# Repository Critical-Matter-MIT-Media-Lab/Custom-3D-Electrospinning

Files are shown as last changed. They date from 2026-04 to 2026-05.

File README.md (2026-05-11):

<div align="center">

# Custom 3D Electrospinning

### A robotic platform for three-dimensional, field-conditioned nanofiber fabrication

*An open hardware + firmware companion to the SIGGRAPH 2026 paper*

**[Electrospun Fields: 3D Nano-Fiber Material Computation as Design Method](#-publications)**

[Critical Matter Group](https://www.media.mit.edu/groups/critical-matter/overview/) · MIT Media Lab

</div>

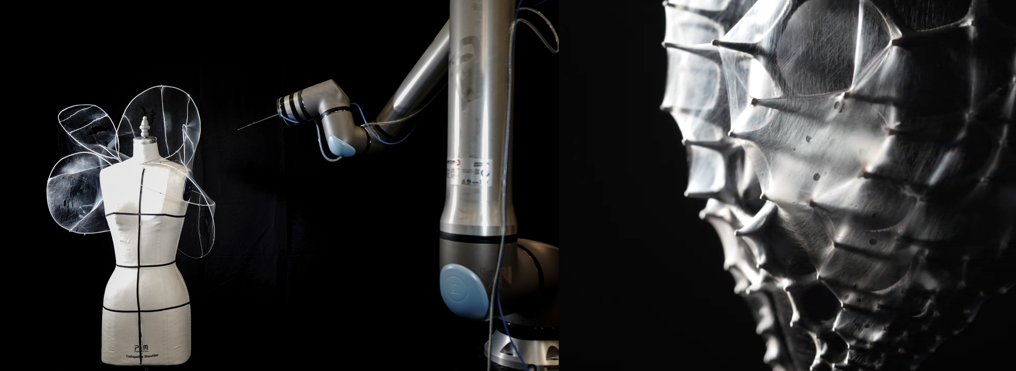
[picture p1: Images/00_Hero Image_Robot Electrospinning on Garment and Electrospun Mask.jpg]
Hero — UR20 robotic arm electrospinning onto a wire garment, alongside a close-up of an electrospun conductive PLA mask


---

## What this repository is

This repo is a **practical companion** to our SIGGRAPH 2026 paper. The paper presents the *why* — a material-computational design method built around electrospinning. This repository is the *how* — the CAD files, firmware, and step-by-step guides you need to build a custom 3D electrospinning rig of your own.

It is intended for:

- **Researchers** who want to reproduce or extend our platform.
- **Designers, artists, and makers** curious about electrospinning as a fabrication method.
- **Students** picking up electrospinning for the first time.

> [!NOTE]
> This repo is meant to **grow over time**. As we publish further work and refine the platform, we will keep adding CAD revisions, firmware features, materials notes, and tutorials.

---

## ▶ Start here: the build tutorial

The fastest way to understand the full system is to watch our build tutorial. It walks through the mechanical, electrical, and software setup end-to-end.

<div align="center">

Watch the tutorial on YouTube (https://youtu.be/FIuRhwlGrd0)

**[▶ Watch on YouTube](https://youtu.be/FIuRhwlGrd0)**

</div>

If you are new to electrospinning, we recommend reading the next two sections first, then watching the tutorial.

---

## What is electrospinning?

Electrospinning is a fabrication technique that uses **strong electric fields to draw a continuous jet of polymer solution into ultra-fine fibers** — typically between a few hundred nanometers and a few micrometers in diameter. The result is a nonwoven fibrous mat with extremely high surface area.

A traditional, fixed setup looks like this:

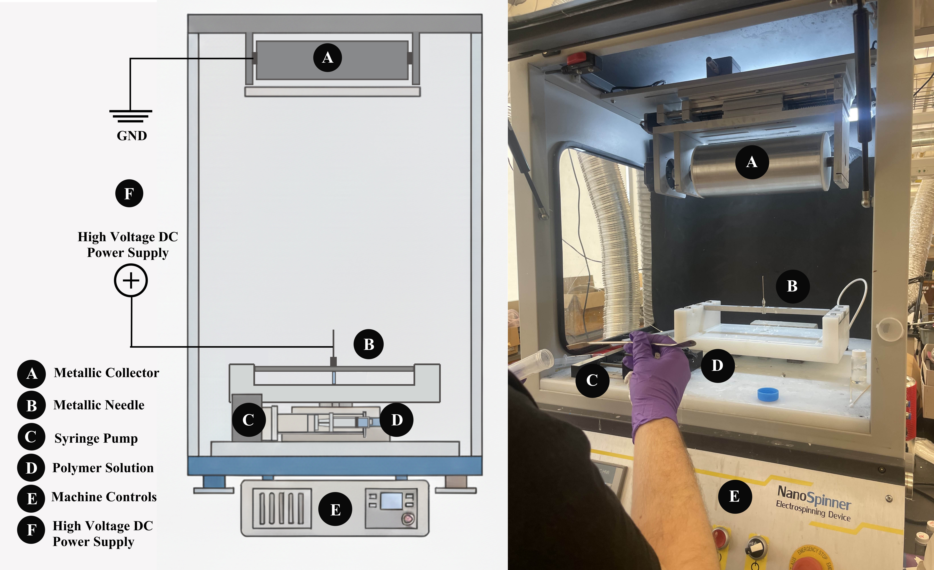
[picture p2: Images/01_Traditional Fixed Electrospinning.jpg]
Traditional fixed electrospinning setup — labeled diagram and lab photograph showing the metallic collector, metallic needle, syringe pump, polymer solution, machine controls, and high-voltage DC power supply


The four functional elements are:

1. **A polymer solution** — a polymer dissolved in a suitable solvent.
2. **A syringe pump** — meters the solution at a controlled flow rate (typically 0.1 – 1 mL/hr).
3. **A high-voltage DC power supply** — connected to a metallic needle, charging the polymer jet (typically **15 – 25 kV**).
4. **A grounded conductive collector** — the substrate the fibers deposit onto.

When the electric field overcomes the surface tension of the droplet at the needle tip, a thin jet is drawn out, whips through the air (stretching as it travels), and the solvent evaporates before deposition — leaving solid nanofibers on the collector.

Electrospinning has been widely used in filtration, tissue engineering, and surface coatings. **What our work explores is its potential as a *spatial, three-dimensional* fabrication method.**

---

## Why a *custom 3D* electrospinning rig?

Conventional electrospinning is essentially a 2D process — fibers fall onto a flat collector below the needle. This makes it excellent for uniform fiber mats, but **fundamentally limits volumetric and topological control**.

In our paper we show that **scaffold curvature shapes the electric field**, and the field shapes where fibers deposit. Convex regions accumulate fibers consistently; concave regions experience *field shielding* and remain bare. To work around that and access complex 3D topologies, the emitter itself needs to move and reorient relative to the scaffold.

That is what this platform does. It mounts an electrospinning end-effector on a six-axis **Universal Robots UR20** arm, with a **localized syringe pump** so flow stays consistent regardless of orientation, and routes high voltage directly to the robot-mounted needle.

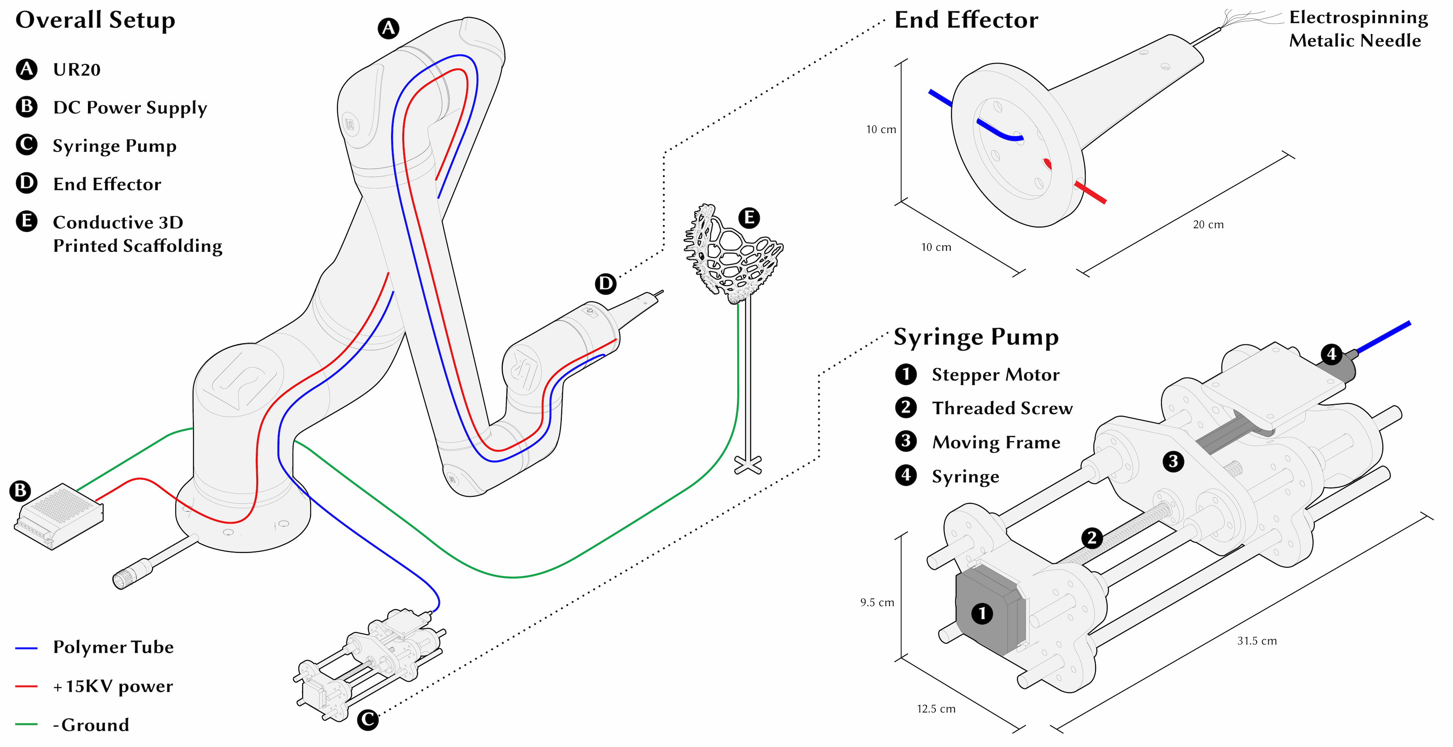
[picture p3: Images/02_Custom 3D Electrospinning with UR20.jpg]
Custom 3D Electrospinning platform — full setup with UR20, DC power supply, syringe pump, end effector, and conductive 3D-printed scaffolding, with detail callouts for the end effector and the syringe pump


| Letter | Component |
|---|---|
| **A** | UR20 six-axis robotic arm |
| **B** | High-voltage DC power supply |
| **C** | Syringe pump (custom — see [`CAD Models/`](CAD%20Models) and [`Arduino Code/`](Arduino%20Code)) |
| **D** | End effector — routes polymer + high voltage to the needle |
| **E** | Conductive 3D-printed scaffolding (the substrate fibers deposit onto) |

> Before building or operating this platform, read the [Safety](#-safety) section below.

---

## What's in this repository

| Folder | What's inside |
|---|---|
| [`Images/`](Images) | Figures from the paper and additional photographs (hero shots, application images, microscopy) |
| [`CAD Models/`](CAD%20Models) | STEP files for every printable / fabricated part of the syringe pump |
| [`Arduino Code/`](Arduino%20Code) | ESP32 firmware for the syringe pump — exposes a Wi-Fi web UI for flow-rate control |
| [`Publications/`](Publications) | Links to publications associated with this platform |

---

## ⚠ Safety

> [!WARNING]
> **Electrospinning involves high-voltage DC and volatile solvents. Read this section before powering on or building anything.**

This platform operates at **up to 25 kV DC** and dispenses polymer solutions prepared with organic solvents. Both are serious hazards and must be respected. The same safety guidance that applies in our paper applies here.

### High voltage

- **Proper electrical insulation and grounding are strictly required.** All conductive paths intended to be at high potential must be sleeved in HV-rated insulation; all conductive paths intended to be at ground must be continuously, verifiably tied to earth ground.
- **Maintain a safe standoff distance.** Never make physical contact with the emitter, polymer jet, or scaffold while the system is energized.
- **De-energize and discharge before touching anything.** Switch off and disconnect the HV supply, then short the needle to ground (with an insulated grounding stick) before approaching the emitter — even a powered-off supply can leave residual charge.
- **One person at the controls.** When the supply is energized, only one trained operator should be near the rig.

### Solvents and ventilation

The polymer solutions used in our paper involve solvents such as **water, formic acid, and lithium bromide**, and may include **calcium chloride** as an additive. Solvent vapor accumulates near the emitter during electrospinning.

- **Operate inside a fume hood** or a dedicated, well-ventilated electrospinning enclosure.
- **No open flames, no sparks, no ignition sources** anywhere near the emitter — solvent vapor + a high-voltage corona is a fire hazard.
- **Wear appropriate PPE:** nitrile gloves, safety glasses, and a lab coat at minimum. Refer to the SDS for each specific solvent you use.

### Robotic arm

This platform integrates a **Universal Robots UR20** six-axis arm.

- **Follow your robot's standard safety protocol.** Define a safety-rated workspace, use the e-stop, and keep humans out of the cell during programmed motion.
- **Coordinate the HV and motion systems.** The robot should not be commanded to move when an operator is positioned to manually adjust the scaffold or the emitter — and HV must be off whenever the cell is entered.

### Bottom line

If you are unsure whether your setup is safe, **stop, ask, and verify** before proceeding. None of the contents of this repository should be treated as a substitute for proper lab training, institutional safety review, or supervision by a qualified electrical and chemical safety officer.

---

## Mechanical setup

The mechanical side of this platform is the **custom syringe pump** — a high-torque, hand-buildable design that mounts to the robot's end effector and pumps polymer solution at electrospinning-grade flow rates (typically 0.1 – 5 mL/hr).

| Element | Role |
|---|---|
| ① Stepper motor | Drives the leadscrew under microstepped pulses from the ESP32 |
| ② Threaded screw (leadscrew) | Converts rotation into linear translation of the moving frame |
| ③ Moving frame | Linear-bearing-guided carriage that pushes the syringe plunger |
| ④ Syringe | Disposable polymer reservoir with a metallic needle |

All mechanical parts are provided as STEP files in [`CAD Models/`](CAD%20Models). See the README in that folder for a part-by-part inventory and printing notes.

---

## Electrical setup

Three independent circuits coexist on this platform — keep them mentally separate:

| Wiring (matches the diagram above) | Carries | Voltage |
|---|---|---|
| **Blue** — polymer tube | Polymer solution from syringe pump → needle | n/a |
| **Red** — high-voltage line | DC power from supply → needle | **+15 to +25 kV** |
| **Green** — ground | DC power supply ground → conductive scaffold | 0 V (earth) |

Plus a low-voltage DC line (not shown in the simplified diagram) powering the ESP32 + stepper driver inside the syringe pump enclosure — covered in [`Arduino Code/README.md`](Arduino%20Code).

> [!CAUTION]
> The high-voltage red line and the polymer tubing both physically run alongside the robot arm to reach the end effector. Use HV-rated insulated tubing, secure all routing, and verify continuity to the grounded scaffold *before* energizing the supply.

---

## Programming setup

The syringe pump is controlled by an **ESP32** running the firmware in [`Arduino Code/`](Arduino%20Code). The firmware:

- Creates its own **Wi-Fi access point** (`ESP32-Syringe`) — no router needed.
- Serves a web UI at `http://192.168.4.1` for **flow rate (mL/hr)**, **direction**, and **syringe size**.
- Drives the stepper at microsecond precision via a hardware timer.

Quickstart:

1. Open `Arduino Code/KeratinStepperMotorControl.ino` in the Arduino IDE.
2. Install the ESP32 board package and upload to your ESP32.
3. Connect your phone or laptop to the `ESP32-Syringe` Wi-Fi network.
4. Open `http://192.168.4.1` in a browser, set your flow rate, press **Start**.

Full wiring map, syringe-size calibration, and the underlying flow-rate formula are in [`Arduino Code/README.md`](Arduino%20Code).

---

## Gallery

A small selection of artifacts produced with this platform — see the paper for the full discussion.

| | |
|---|---|
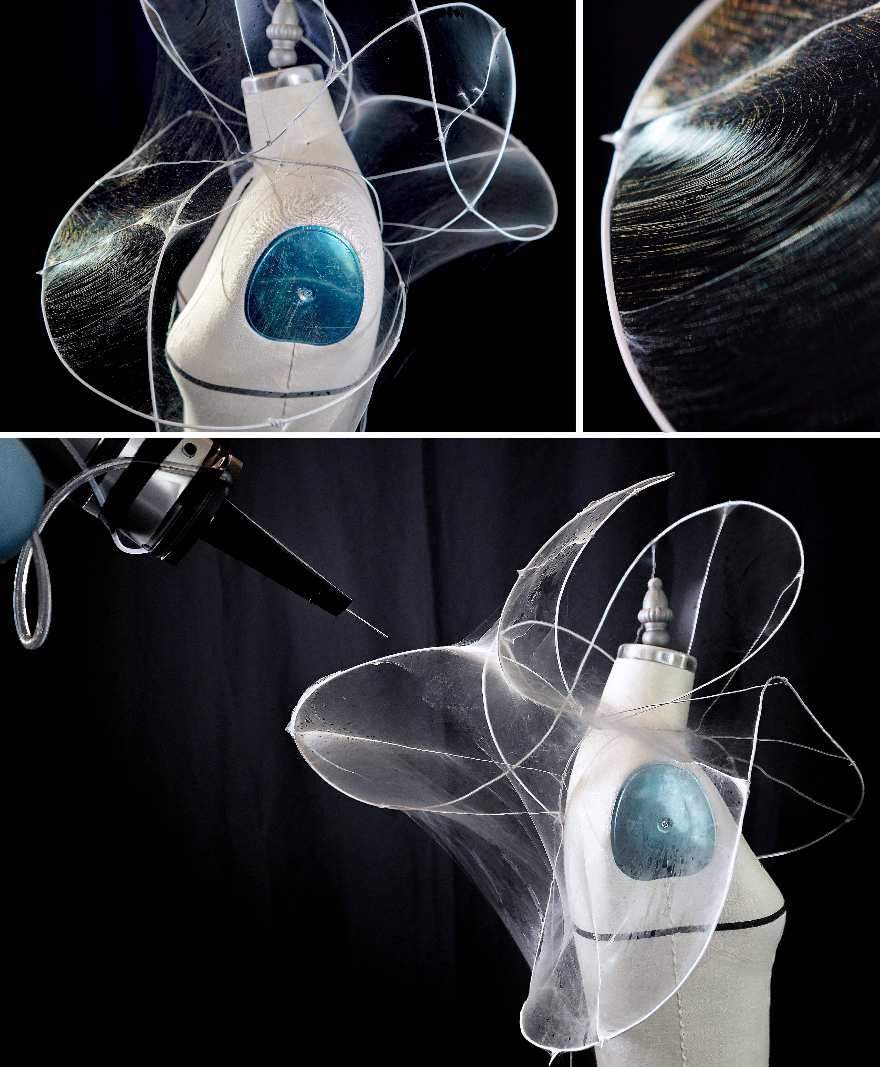
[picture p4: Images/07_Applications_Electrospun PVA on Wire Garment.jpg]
Electrospun PVA on a wire garment, draped on a mannequin
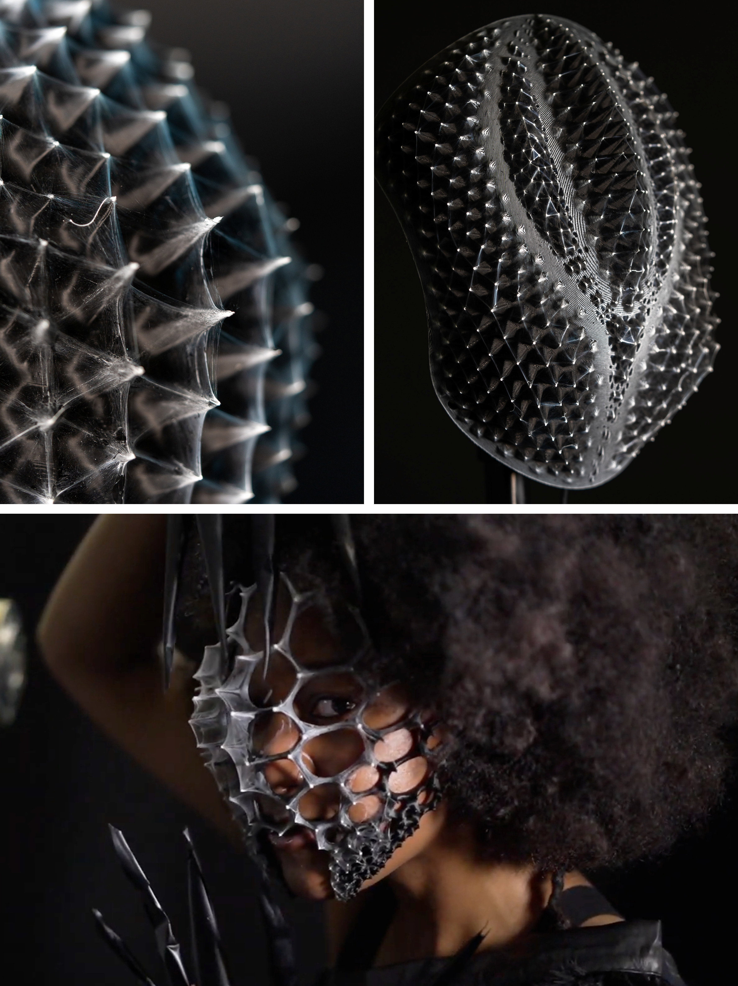
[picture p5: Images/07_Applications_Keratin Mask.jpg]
Electrospun keratin face mask, close-up of fiber surface
|  |  |
| **Electrospun PVA on a wire garment** | **Keratin–PEO face mask** |
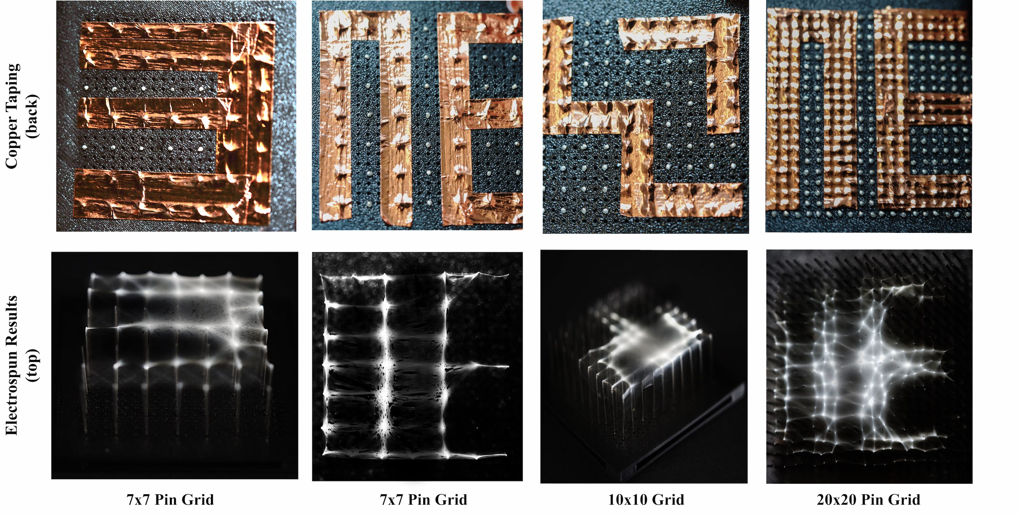
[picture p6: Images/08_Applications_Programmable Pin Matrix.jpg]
Programmable pin-matrix collector with selectively electrospun regions
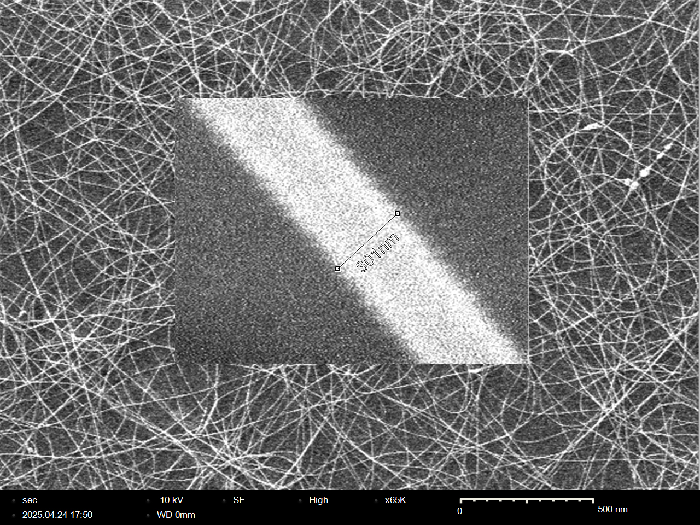
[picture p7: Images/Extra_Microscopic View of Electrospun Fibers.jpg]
Microscopic view of electrospun fibers showing nanoscale fiber morphology
|  |  |
| **Programmable pin-matrix collector** | **Microscopy of electrospun fibers** |

---

## Publications

Work from this platform is documented in the following publications. We host **links only** — please cite the canonical version of record at the publisher when available.

- **Wan, Mahmoud, Mutis, Velho, Xing, Farahi.** *Electrospun Fields: 3D Nano-Fiber Material Computation as Design Method.* SIGGRAPH '26 Art Papers. *ACM Digital Library link coming soon.*

A full list with citation entries lives in [`Publications/README.md`](Publications).

---

## Citation

This paper will appear in the ACM Digital Library shortly. The entry below will be updated with the DOI when available — for now, please use this preliminary BibTeX:

```bibtex
@inproceedings{wan2026electrospun,
  title     = {Electrospun Fields: 3D Nano-Fiber Material Computation as Design Method},
  author    = {Wan, Wai Lok and Mahmoud, Ayah and Mutis, Sergio and Velho, Avantika and Xing, Annie and Farahi, Behnaz},
  booktitle = {ACM SIGGRAPH 2026 Art Papers},
  year      = {2026},
  publisher = {ACM},
  address   = {New York, NY, USA},
  note      = {In press}
  % doi    = {TODO: add DOI when ACM DL link is live}
  % url    = {TODO: add ACM DL URL when available}
}
```

---

## Authors and Acknowledgements

| Author | Affiliation |
|---|---|
| Wai Lok Wan | MIT |
| Ayah Mahmoud | MIT |
| Sergio Mutis | MIT |
| Avantika Velho | Harvard University |
| Annie Xing | Harvard University |
| James Xiao | MIT |
| Behnaz Farahi (Director, [Critical Matter Group](https://www.media.mit.edu/groups/critical-matter/overview/)) | MIT Media Lab |

For questions, collaboration inquiries, or to flag issues with the documentation, please open a GitHub issue on this repository.

### Acknowledgements

We would like to acknowledge Frank (Haotian) Cong and Berfin Ataman for their invaluable contributions to the early development of the system. Our thanks also go to Paolo Salvagione for his guidance on mechanical and electrical engineering. This research was developed in collaboration with the Rutledge Research Group at the MIT Department of Chemical Engineering; we extend our sincere gratitude to Nathan Ewell and Greg Rutledge for their expertise and generous assistance. Finally, we gratefully acknowledge the MIT–LUMA Grant for their generous financial support.

---

## License

© 2026 Critical Matter Group, MIT Media Lab.

This repository — including its source code, CAD files, images, and written documentation — is released under the [Creative Commons Attribution 4.0 International License (CC-BY-4.0)](LICENSE). You are free to share and adapt the contents for any purpose, including commercially, **provided you give appropriate credit to the Critical Matter Group**.

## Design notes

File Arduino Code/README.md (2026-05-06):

# Arduino Code — ESP32 Syringe Pump Firmware

This folder contains the firmware that drives the custom syringe pump.

It runs on an **ESP32**, drives a **NEMA-17 stepper** through a **DRV8825** driver, and exposes a small **Wi-Fi web UI** for setting flow rate, direction, and syringe size — no router needed.

---

## File

- `KeratinStepperMotorControl.ino` — single-file Arduino sketch. The name is a leftover from our keratin-electrospinning experiments; the firmware itself is fully general and works for any polymer.

---

## What it does

- **Creates a Wi-Fi access point** named `ESP32-Syringe` (open, no password by default).
- **Serves a web UI at `http://192.168.4.1`** with controls for:
  - **Start / Pause**
  - **Direction** (clockwise = dispense, counter-clockwise = retract)
  - **Syringe size** (mm of plunger travel per mL)
  - **Flow rate** (mL/hr)
- **Drives the stepper at microsecond precision** via an ESP32 hardware timer running at 1 MHz. The web UI never touches the step pin — it only updates the timer's half-period.

---

## Hardware

| Component | Spec |
|---|---|
| Microcontroller | ESP32 (any DevKit-style board with the standard pinout) |
| Stepper driver | DRV8825 with at least 12–24 V motor supply and 64× microstepping enabled |
| Stepper motor | NEMA-17 bipolar, 200 steps/rev |
| Leadscrew | T8 × 2 (2 mm lead) — see [`CAD Models/`](../CAD%20Models) |

### Wiring

| ESP32 GPIO | DRV8825 pin | Notes |
|---|---|---|
| GPIO **17** | `STEP` | Pulse train output |
| GPIO **16** | `DIR` | HIGH = clockwise, LOW = counter-clockwise |
| GND | `GND` (logic) | Common ground with ESP32 |
| — | `SLEEP` ↔ `RESET` | Tie together to keep the driver awake |
| — | `M0`, `M1`, `M2` | All HIGH for **64× microstepping** (or pull `M2` HIGH and tie `M0/M1` per the DRV8825 datasheet — the firmware assumes 64×) |

The motor power supply (12–24 V) connects to the `VMOT` / `GND` pair on the driver; **be sure to add the recommended 100 µF electrolytic capacitor across `VMOT` and `GND`** as close to the driver as possible.

> [!CAUTION]
> Make sure the stepper logic ground and the motor power ground are common with the ESP32 ground. Floating grounds are a common cause of missed steps and erratic behavior.

---

## How the flow rate is computed

The firmware converts the user-set flow rate (mL/hr) into a step pulse half-period (µs) using:

```
halfPeriodUs = (281,250 × mm_per_mL) / mL_per_hr
```

This number comes from the gearing math at the top of the sketch:

- **Stepper:** 200 steps/rev × 64 microsteps = **12,800 µsteps/rev**
- **Leadscrew:** **2 mm/rev**
- **=> 6,400 µsteps per mm**

If you change the leadscrew, microstepping, or stepper, **update the constant accordingly** — see the comment block at the top of `KeratinStepperMotorControl.ino`.

### Syringe-size calibration

The web UI's **Syringe size** dropdown sets `mm_per_mL` — the millimeters of plunger travel that correspond to 1 mL of dispensed volume. Defaults included:

| Option | Use when |
|---|---|
| `1 mm = 1 mL` | (Default — calibrated for our typical disposable syringe) |
| `2 mm = 1 mL` | Smaller-bore syringes |
| `0.5 mm = 1 mL` | Larger-bore syringes |

To add a new option, edit the `<select id="syringe">` block in the embedded HTML inside the `.ino` file (search for `CHANGE THESE FOR CHANGING SYRINGE OPTIONS`).

> [!TIP]
> The most reliable way to calibrate a new syringe is empirical: dispense for a fixed time at a known mL/hr setting, weigh the output, and adjust `mm_per_mL` until the weight matches the expected volume.

---

## Quickstart

1. **Install the ESP32 board package** in the Arduino IDE.
   - `File → Preferences → Additional Boards Manager URLs:` add `https://espressif.github.io/arduino-esp32/package_esp32_index.json`
   - `Tools → Board Manager`, search **esp32**, install **esp32 by Espressif Systems**.
2. **Open `KeratinStepperMotorControl.ino`** in the Arduino IDE.
3. **Select your ESP32 board** under `Tools → Board → ESP32 Arduino`.
4. **Upload** to the ESP32.
5. Open the **Serial Monitor** at 115200 baud — you should see the access-point IP printed (`192.168.4.1`).
6. **Connect your phone or laptop** to the `ESP32-Syringe` Wi-Fi network.
7. Open `http://192.168.4.1` in a browser. Set your **syringe size** and **flow rate**, press **Apply**, then **Start**.

---

## Customizing the access point

Edit the constants at the top of the `.ino`:

```c
const char* AP_SSID = "ESP32-Syringe";   // Network name
const char* AP_PASS = "";                // 8+ chars to enable WPA2; empty = open
const uint8_t AP_CHANNEL = 6;            // Wi-Fi channel
```

If you set a password, it must be **at least 8 characters** — otherwise the firmware falls back to an open network.

---

## License

This firmware is released under the [Creative Commons Attribution 4.0 International License (CC-BY-4.0)](../LICENSE). © 2026 Critical Matter Group, MIT Media Lab. Please credit the Critical Matter Group when reusing or modifying.

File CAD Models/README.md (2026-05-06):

# CAD Models — Custom Syringe Pump

This folder contains the STEP files for every part of the custom syringe pump used in our 3D electrospinning platform. The pump is mounted on the UR20 robot's end effector and pumps polymer solution at electrospinning-grade flow rates (typically **0.1 – 5 mL/hr**) regardless of tool orientation.

For a labeled overview of the syringe pump in context, see the [main README](../README.md#mechanical-setup) and the figure [`Images/02_Custom 3D Electrospinning with UR20.jpg`](../Images/02_Custom%203D%20Electrospinning%20with%20UR20.jpg).

---

## File format

All parts are exported from Onshape as **STEP (`.step`)** files. STEP is a neutral CAD format and can be opened in any major CAD package — Fusion 360, SolidWorks, Onshape, FreeCAD, Rhino, etc. — and converted to STL for 3D printing.

> [!TIP]
> Looking for the live, editable Onshape source? Open an issue on this repo and we can share the public document link.

---

## Part inventory

The pump consists of three categories of parts: **3D-printed structural parts**, **off-the-shelf hardware**, and the **stepper motor assembly**. The "Source" column tells you what to do with each.

### Structural (3D-print these)

| File | Part | Notes |
|---|---|---|
| `Part Studio 1 - Head Support.step` | Head support | Mounts the stepper motor and one end of the linear rails |
| `Part Studio 1 - End Support.step` | End support | Mounts the other end of the linear rails and supports the syringe tip |
| `Part Studio 1 - Pusher.step` | Pusher | The moving carriage that pushes the syringe plunger |
| `Part Studio 1 - Syringe Clamp.step` | Syringe clamp | Holds the syringe body in place against the End Support |
| `Part Studio 1 - Flange Connector.step` (and variants `(1)`–`(7)`) | Flange connectors | Small adapter parts — print one of each variant as needed for the linear bearings, leadscrew nut, and end-of-rail caps |

**Recommended print settings (starting point — tune for your printer):**

- Material: **PLA** or **PETG** (PETG preferred if the pump will be near solvents)
- Layer height: 0.2 mm
- Walls: 4
- Infill: 40 % (gyroid or grid)
- Supports: only where overhangs exceed 50°

### Off-the-shelf hardware (purchase these)

| File | Part | Typical specification |
|---|---|---|
| `Part Studio 1 - Lead Screw.step` | Leadscrew | **2 mm lead** trapezoidal leadscrew (T8 × 2). The firmware assumes 2 mm/rev — see [`Arduino Code/`](../Arduino%20Code) before changing this |
| `Part Studio 1 - Steel Rod.step` (×4 variants) | Smooth linear rails | Hardened steel, diameter to match the linear bearings (commonly 8 mm) |
| `Part Studio 1 - Linear Bearing.step` (×2 variants) | Linear bearings | LM-series ball bearings sized to the rails |

### Stepper assembly

| File | Part | Notes |
|---|---|---|
| `Part Studio 1 - ActualStepper.step` | Stepper motor reference geometry | NEMA-17 bipolar stepper, 200 steps/rev. The firmware drives this at **64× microstepping** via a DRV8825 driver — see [`Arduino Code/`](../Arduino%20Code) for wiring and pulse timing |

---

## Assembly at a glance

```
Head Support  ──[ stepper ]──┐                                ┌──  End Support
                             │                                │
                  ┌──────────┴────[ leadscrew ]────────────┐  │
                  │                                          │  │
                  └──[ Pusher (rides on linear bearings) ]──┘  │
                             │                                │
                  ┌──────────┴──── steel rails ───────────────┴──── (×2)
                  │
                  └────────────[ syringe + clamp ]─────────────────
```

1. Mount the stepper motor to the **Head Support** with M3 screws.
2. Couple the stepper shaft to the **leadscrew** with a flexible coupler.
3. Insert the **steel rails** through the Head Support and End Support, capturing the **linear bearings** through the Pusher.
4. Thread the leadscrew through the leadscrew nut on the Pusher. Cap the far end at the End Support.
5. Seat the **syringe** in the End Support and lock it down with the **Syringe Clamp**. The syringe plunger should sit centered against the Pusher.
6. Wire the stepper to your DRV8825 driver and ESP32 — see [`Arduino Code/README.md`](../Arduino%20Code).

---

## Notes for modification

- **Different syringe size?** No CAD changes needed for most plastic syringes — the firmware exposes a `mm per mL` calibration value in its web UI to compensate. See [`Arduino Code/`](../Arduino%20Code).
- **Different leadscrew lead?** You **must** update the firmware constant: the conversion `6,400 µsteps per mm` assumes 200 steps/rev × 64 microsteps × (1 / 2 mm per rev). See the comments at the top of `KeratinStepperMotorControl.ino`.
- **Different stepper or microstepping?** Same — see firmware constants.

---

## License

These CAD files are released under the [Creative Commons Attribution 4.0 International License (CC-BY-4.0)](../LICENSE). © 2026 Critical Matter Group, MIT Media Lab. Please credit the Critical Matter Group when reusing or remixing.

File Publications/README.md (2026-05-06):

# Publications

A running list of publications associated with this platform. We host **links only** — please cite the canonical version of record at the publisher.

This list will grow as new work comes out.

---

## 2026

### Electrospun Fields: 3D Nano-Fiber Material Computation as Design Method

**Wai Lok Wan, Ayah Mahmoud, Sergio Mutis, Avantika Velho, Annie Xing, Behnaz Farahi.**
*ACM SIGGRAPH 2026 Art Papers.*

The original paper introducing this platform. Presents (1) a reusable design method for field-conditioned electrospinning, (2) a bio-compatible material catalog defining an operating envelope, (3) a scaffold taxonomy linking geometry to deposition behavior, and (4) the reproducible robotic platform documented in this repository.

- **Status:** In press — *ACM Digital Library link coming soon.*
- **Tutorial video:** [youtu.be/paKA7W3roEg](https://youtu.be/paKA7W3roEg)
- **Code & CAD:** this repository
- **BibTeX:** see the [main README](../README.md#citation)

---

## Coming soon

We are actively working on follow-up publications extending this platform. Check back here, or watch the repository on GitHub to be notified of updates.

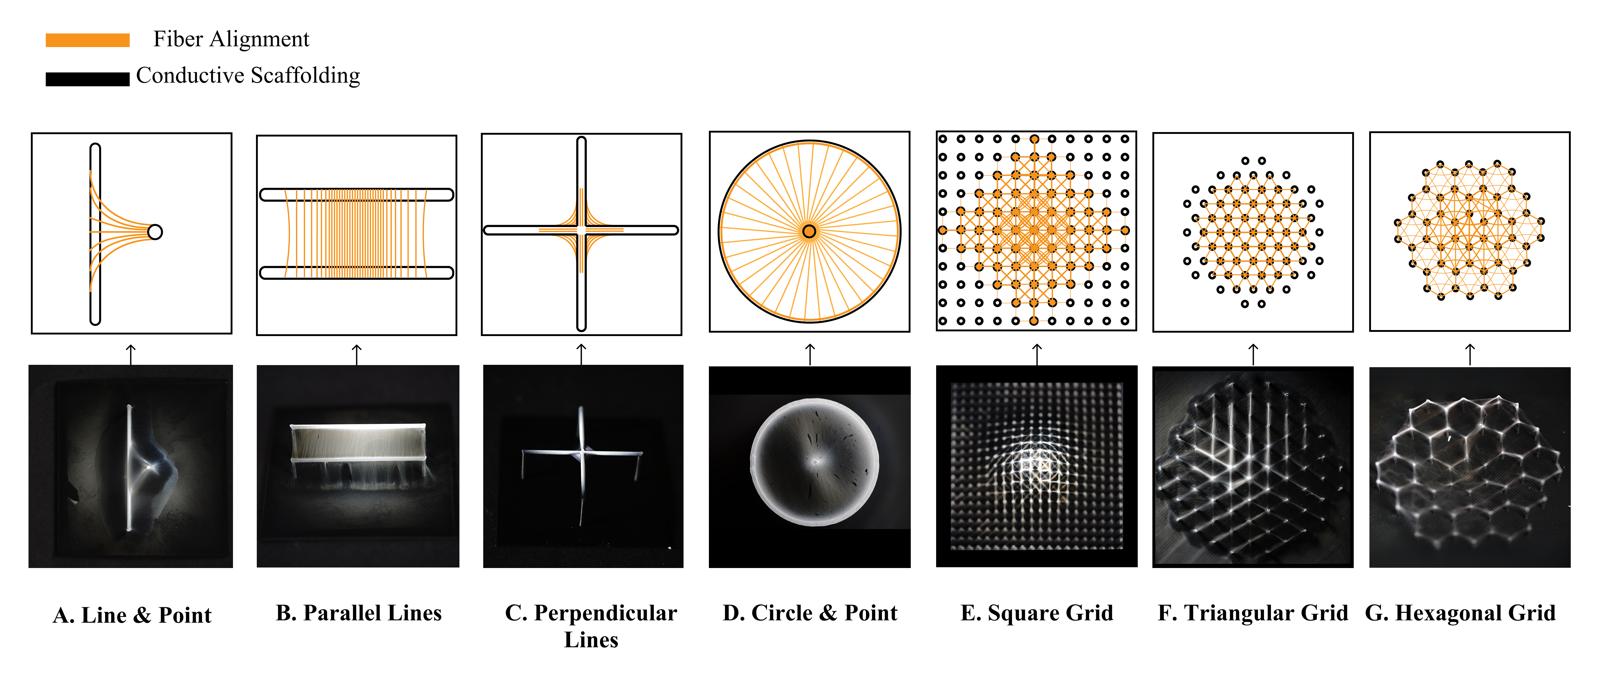
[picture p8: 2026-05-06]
Images/05_Fiber-Alignment Diagrams.jpg

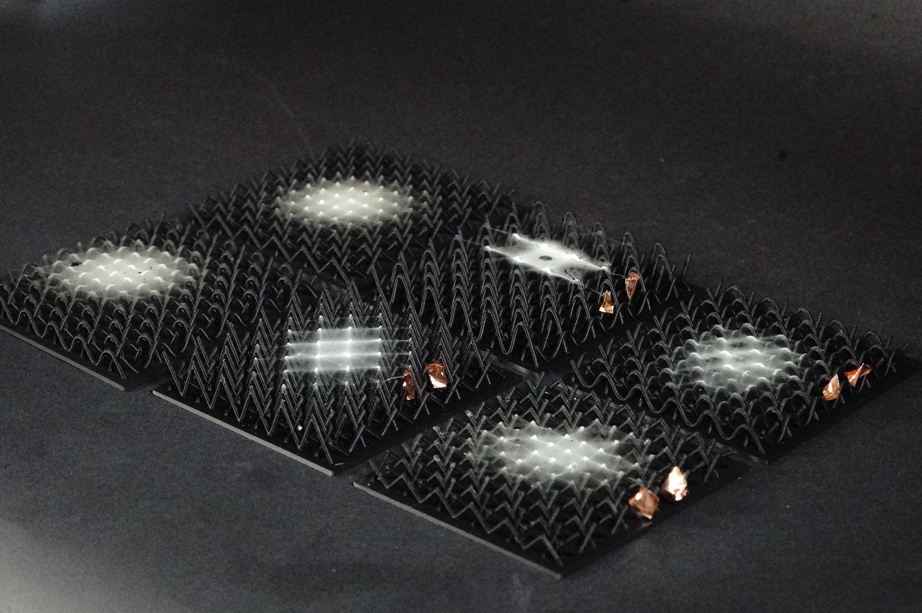
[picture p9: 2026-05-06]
Images/Extra_Preliminary Electrospun Studies.JPG

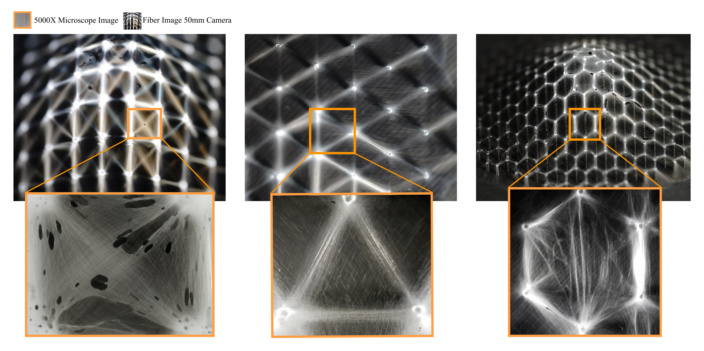
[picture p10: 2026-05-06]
Images/06_Close-Ups of Fiber Deposition Behaviours.jpg

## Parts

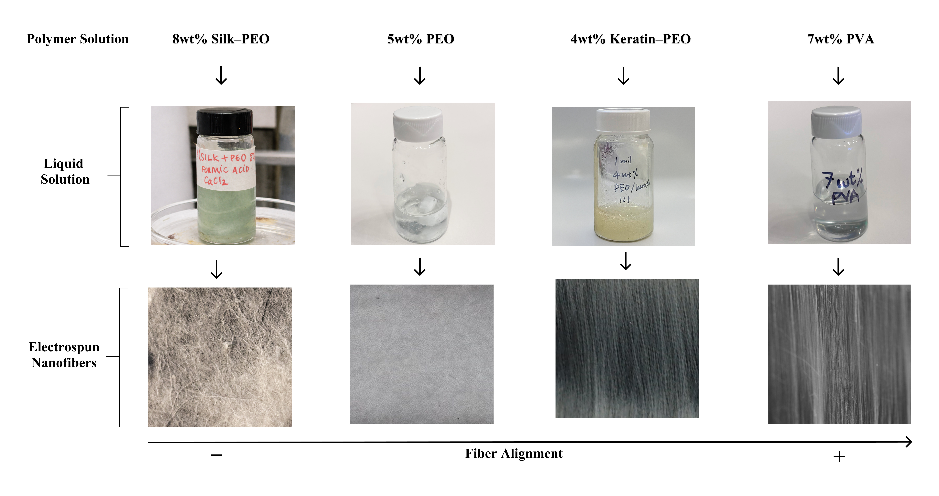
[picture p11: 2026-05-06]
Images/03_Material-Catalog.jpg

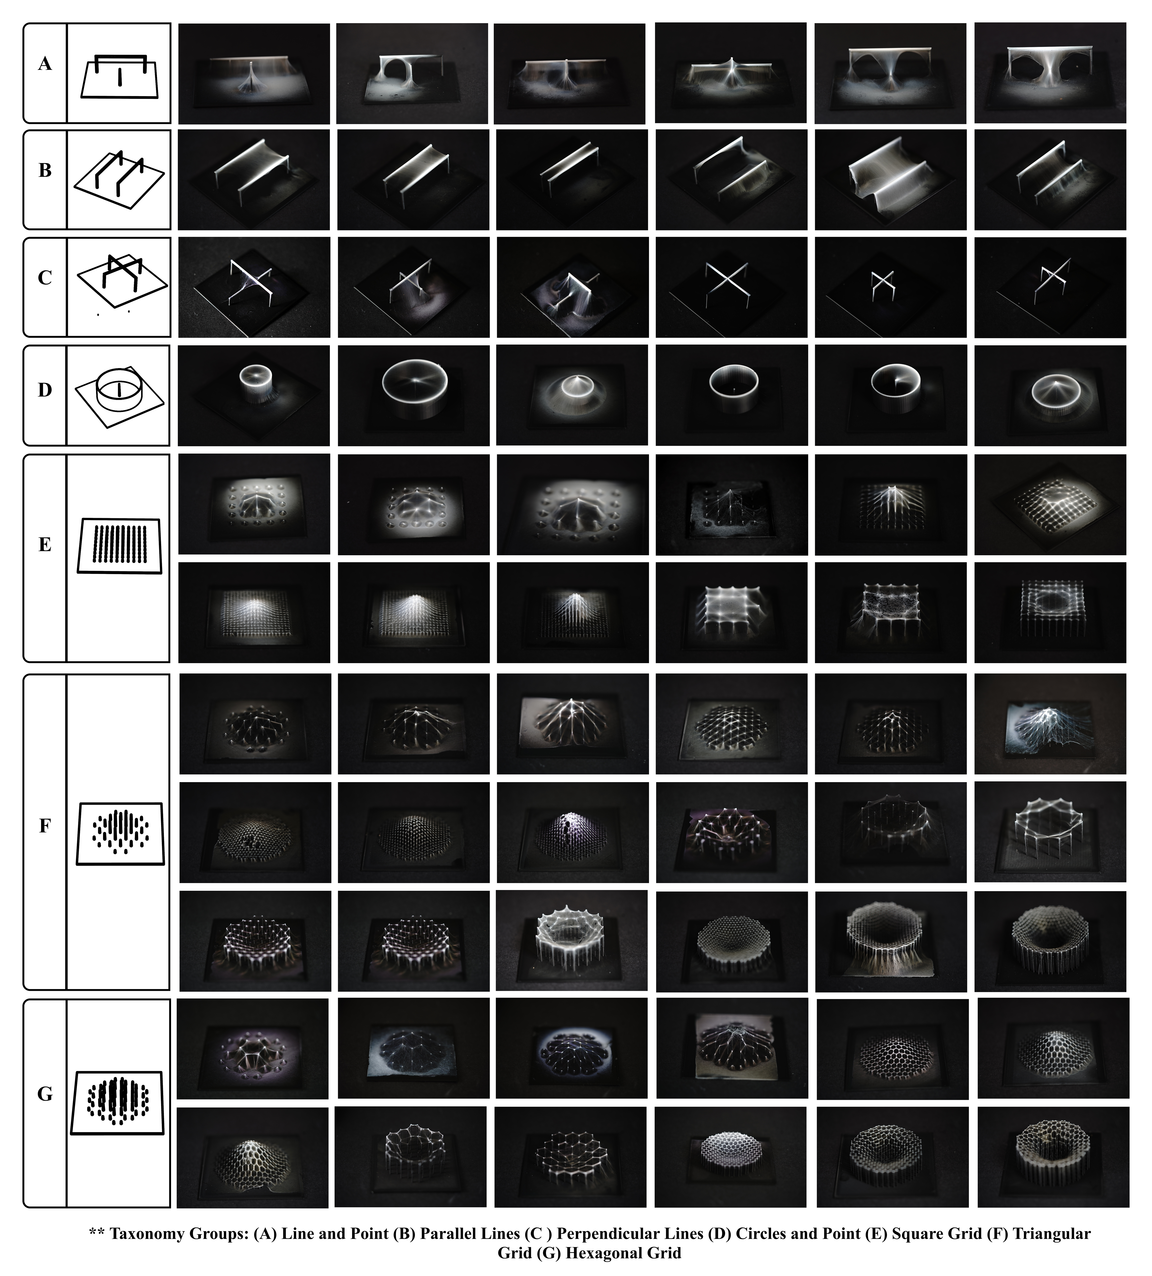
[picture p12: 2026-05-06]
Images/04_Taxonomy of Scaffolds and Material Deposition.jpg

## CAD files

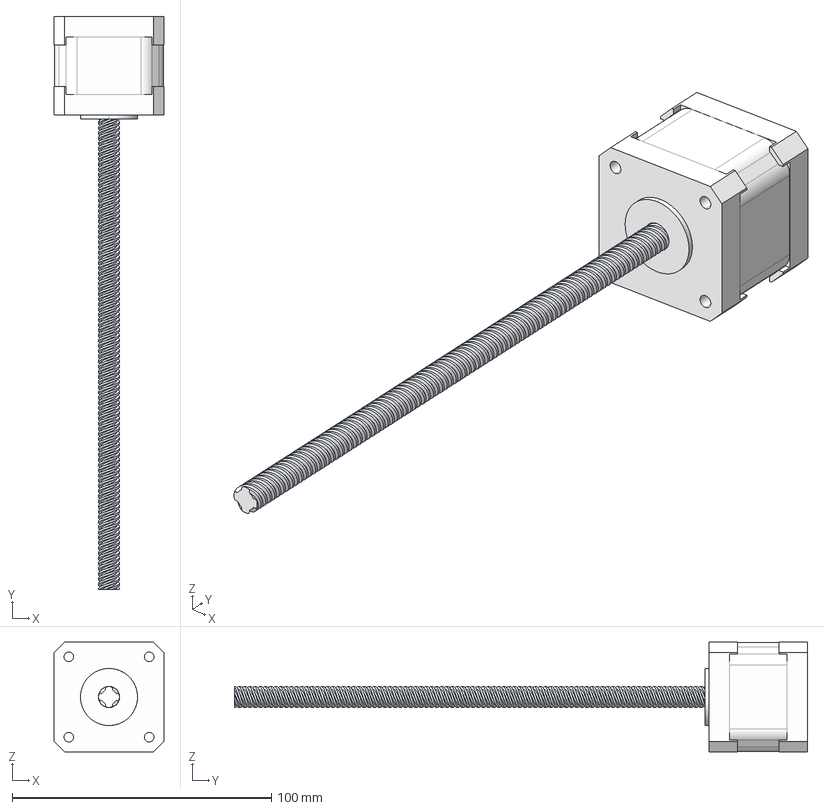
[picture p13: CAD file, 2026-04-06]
CAD Models/Part Studio 1 - ActualStepper.step
42.3 x 221.0 x 42.3 mm

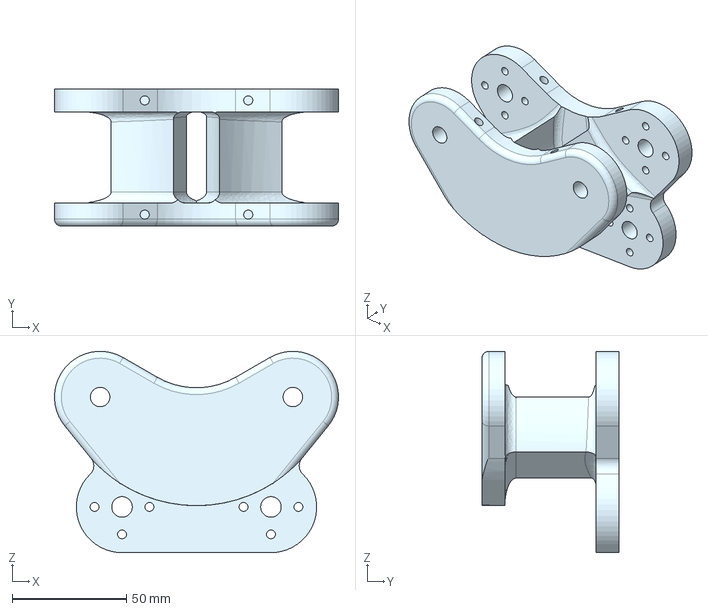
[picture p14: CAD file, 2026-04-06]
CAD Models/Part Studio 1 - End Support.step
124.3 x 60.0 x 88.1 mm

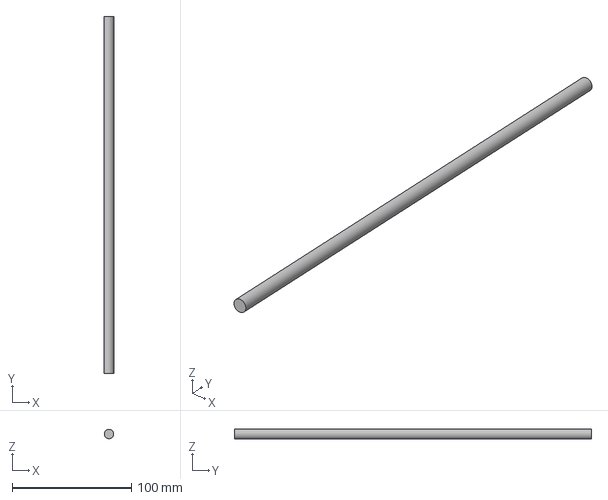
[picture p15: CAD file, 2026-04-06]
CAD Models/Part Studio 1 - Steel Rod.step
8.00 x 300.0 x 7.99 mm

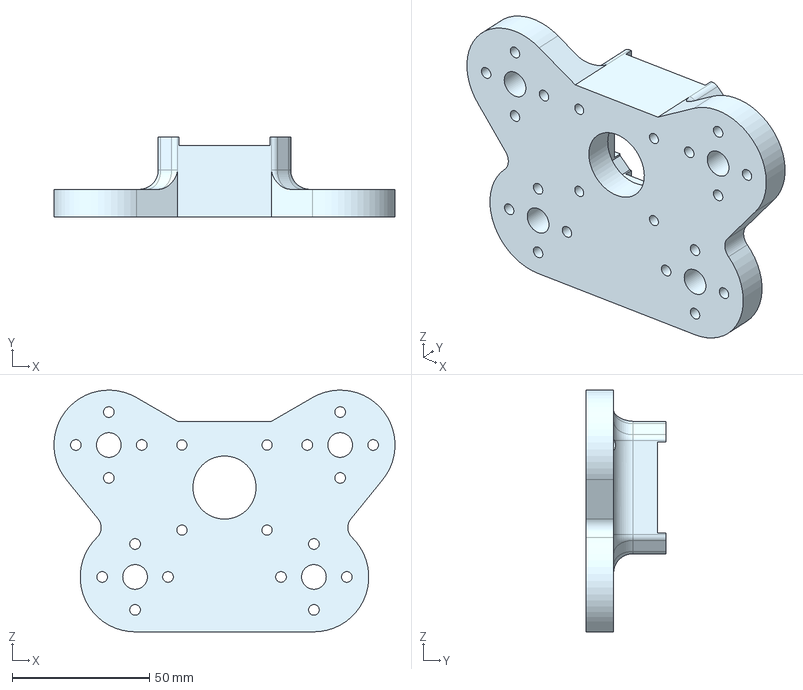
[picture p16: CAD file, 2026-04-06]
CAD Models/Part Studio 1 - Head Support.step
124.3 x 29.0 x 88.1 mm

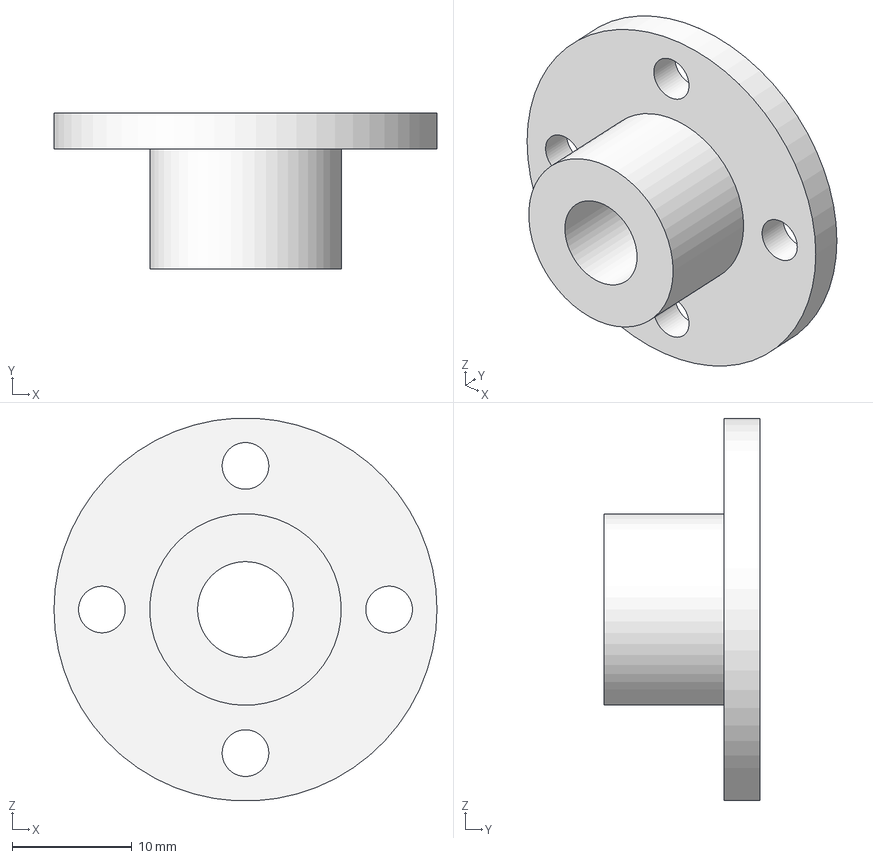
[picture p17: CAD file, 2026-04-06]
CAD Models/Part Studio 1 - Flange Connector.step
32.0 x 13.0 x 32.0 mm

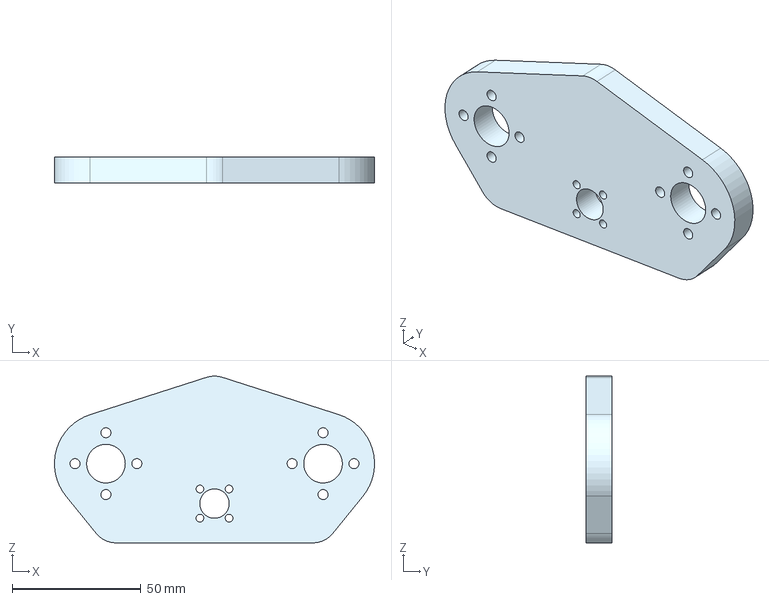
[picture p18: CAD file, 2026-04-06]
CAD Models/Part Studio 1 - Pusher.step
124.3 x 10.0 x 64.7 mm

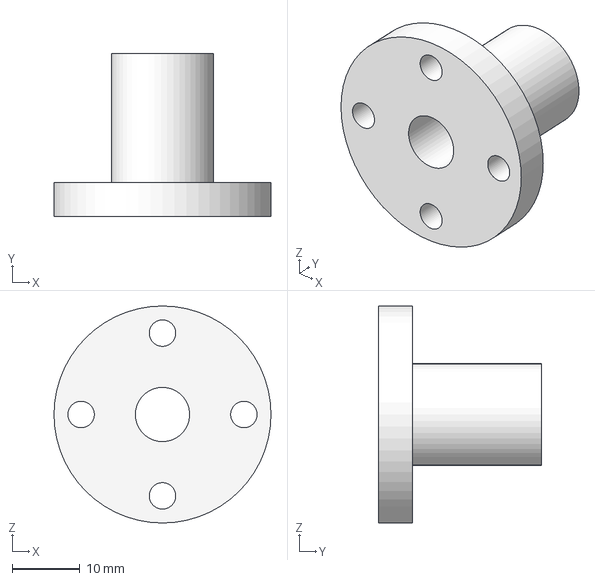
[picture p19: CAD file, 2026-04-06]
CAD Models/Part Studio 1 - Linear Bearing.step
32.0 x 24.0 x 32.0 mm

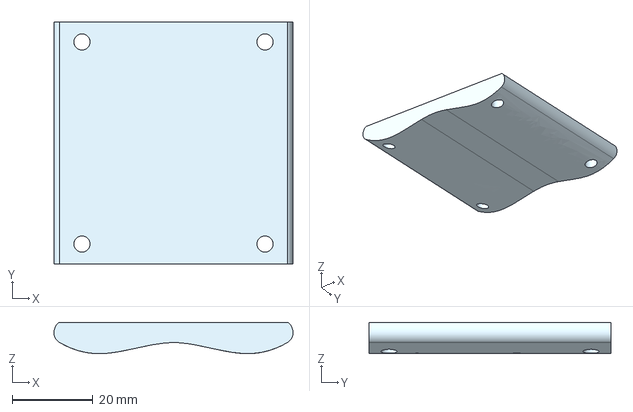
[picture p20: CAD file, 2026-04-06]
CAD Models/Part Studio 1 - Syringe Clamp.step
59.1 x 60.0 x 7.74 mm

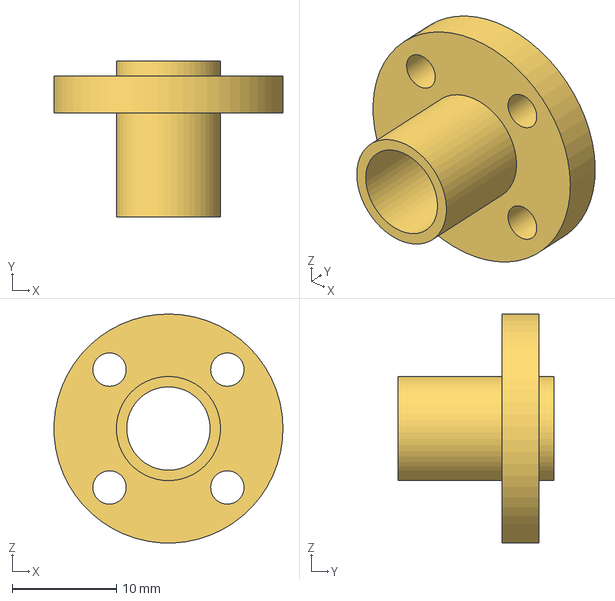
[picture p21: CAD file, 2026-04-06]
CAD Models/Part Studio 1 - Lead Screw.step
22.0 x 15.0 x 22.0 mm

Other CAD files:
CAD Models/Part Studio 1 - Flange Connector (6).step
CAD Models/Part Studio 1 - Steel Rod (2).step
CAD Models/Part Studio 1 - Flange Connector (4).step
CAD Models/Part Studio 1 - Flange Connector (1).step
CAD Models/Part Studio 1 - Linear Bearing (1).step
CAD Models/Part Studio 1 - Flange Connector (7).step
CAD Models/Part Studio 1 - Steel Rod (1).step
CAD Models/Part Studio 1 - Flange Connector (3).step
CAD Models/Part Studio 1 - Flange Connector (5).step
CAD Models/Part Studio 1 - Flange Connector (2).step
CAD Models/Part Studio 1 - Steel Rod (3).step

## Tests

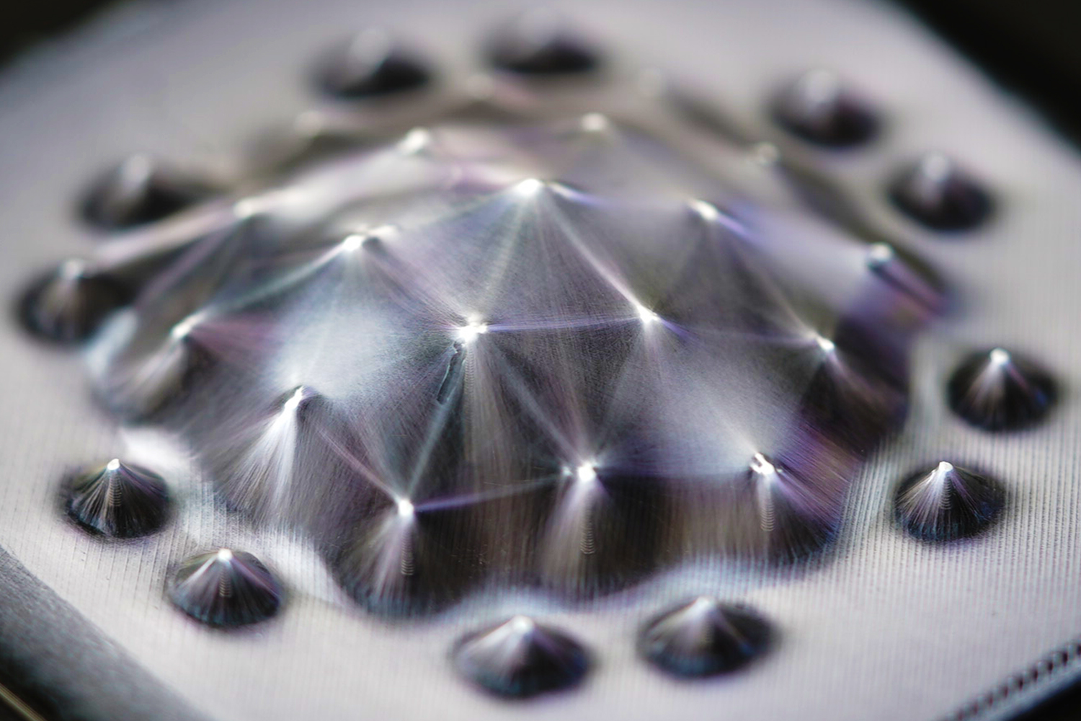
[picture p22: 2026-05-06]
Images/Extra_Detailed Shot of Taxonomy Experiment 2.jpg

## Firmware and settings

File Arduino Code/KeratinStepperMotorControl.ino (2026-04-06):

/*
  ESP32 + DRV8825 Syringe Pump Controller (SoftAP mode)
  - ESP32 creates its own Wi-Fi network (no router).
  - Connect your laptop/phone to that network, then open http://192.168.4.1
  - Control: Start/Pause, Direction, Speed (mL/hr), Syringe size
  - Smooth pulses via hardware timer @1 MHz.
  - UI won’t overwrite inputs while you type (polling pauses on focus).

  Mechanics:
    - Stepper: 200 steps/rev × 64 microsteps = 12,800 µsteps/rev
    - Worm gear: 2 mm/rev
    - => 6,400 µsteps per mm
    - Base formula for half-period (µs):
        halfPeriodUs = (281250 * mm_per_mL) / (mL/hr)

  Syringe size (mm per mL):
    - Example: 1 mL per 1 mm  -> factor = 1
    - Example: 1 mL per 2 mm -> factor = 2
*/

#include <WiFi.h>
#include <WebServer.h>

// ============ SoftAP CONFIG ============
const char* AP_SSID = "ESP32-Syringe";  
const char* AP_PASS = "";               
const uint8_t AP_CHANNEL = 6;
const bool AP_HIDDEN = false;
const uint8_t AP_MAX_CONN = 4;
// ======================================

// GPIOs
const int DIR_PIN  = 16;
const int STEP_PIN = 17;

// State
volatile uint32_t halfPeriodUs = 2812; // default ≈100 mL/hr with 1 mm/mL
volatile bool     running      = false;
volatile bool     dirCW        = true;
volatile float    syringe_mm_per_mL = 1.0;  // default syringe: 1 mm/mL

WebServer server(80);

// Timer
hw_timer_t* timer = nullptr;
portMUX_TYPE timerMux = portMUX_INITIALIZER_UNLOCKED;
volatile bool stepState = false;

// ================== ISR ==================
void IRAM_ATTR onTimer() {
  portENTER_CRITICAL_ISR(&timerMux);
  if (running) {
    stepState = !stepState;
    if (stepState) {
      GPIO.out_w1ts = (1UL << STEP_PIN);
    } else {
      GPIO.out_w1tc = (1UL << STEP_PIN);
    }
  } else {
    stepState = false;
    GPIO.out_w1tc = (1UL << STEP_PIN);
  }
  timerAlarmWrite(timer, halfPeriodUs, true);
  portEXIT_CRITICAL_ISR(&timerMux);
}

// ================== HTML UI ==================
const char* PAGE = R"HTML(
<!doctype html>
<html>
<head>
<meta charset="utf-8"/>
<meta name="viewport" content="width=device-width,initial-scale=1"/>
<title>ESP32 Syringe Pump</title>
<style>
  body{font-family:system-ui,Segoe UI,Arial,sans-serif;max-width:720px;margin:40px auto;padding:0 16px}
  h1{font-size:1.25rem;margin-bottom:12px}
  .card{border:1px solid #ddd;border-radius:12px;padding:16px;box-shadow:0 2px 6px rgba(0,0,0,.06)}
  .row{display:flex;gap:12px;align-items:center;margin:12px 0;flex-wrap:wrap}
  label{min-width:160px}
  input[type="number"],select{width:160px;padding:6px}
  button{padding:8px 12px;cursor:pointer;border-radius:8px;border:1px solid #ccc;background:#f7f7f7}
  .on{background:#d7ffe0;border-color:#6ccf86}
  .off{background:#ffe0e0;border-color:#ff8c8c}
  .muted{color:#666}
</style>
</head>
<body>
  <h1>ESP32 Syringe Pump</h1>
  <div class="card">
    <div class="row">
      <label>Status:</label>
      <span id="status" class="muted">loading...</span>
    </div>
    <div class="row">
      <label>Run / Pause:</label>
      <button id="btnRun" class="on">Start</button>
      <button id="btnPause" class="off">Pause</button>
    </div>
    <div class="row">
      <label>Direction:</label>
      <select id="dir">
        <option value="1">Clockwise (DIR=HIGH)</option>
        <option value="0">Counter-Clockwise (DIR=LOW)</option>
      </select>
    </div>
    <div class="row">
      <label>Syringe size:</label>
      <select id="syringe">
        <option value="1">1 mm = 1 mL</option> <!-- CHANGE THESE FOR CHANGING SYRINGE OPTIONS -->
        <option value="2">2 mm = 1 mL</option> <!-- CHANGE THESE FOR CHANGING SYRINGE OPTIONS -->
        <option value="0.5">0.5 mm = 1 mL</option> <!-- CHANGE THESE FOR CHANGING SYRINGE OPTIONS -->
      </select>
    </div>
    <div class="row">
      <label>Flow Rate (mL/hr):</label>
      <input id="mlhr" type="number" min="0.1" max="100000" step="0.1"/>
    </div>
    <div class="row">
      <button id="apply">Apply</button>
    </div>
    <p class="muted">Enter flow in mL/hr. Conversion depends on syringe size.</p>
  </div>

<script>
let editing=false, editingDir=false, editingSyr=false;
const statusEl = document.getElementById('status');
const dirEl    = document.getElementById('dir');
const mlhrEl   = document.getElementById('mlhr');
const syringeEl= document.getElementById('syringe');

let pollId = null;
function startPoll(){ stopPoll(); pollId=setInterval(getStatus,1000); }
function stopPoll(){ if(pollId){ clearInterval(pollId); pollId=null; } }

mlhrEl.addEventListener('focus', ()=>{ editing=true; stopPoll(); });
mlhrEl.addEventListener('blur',  ()=>{ editing=false; startPoll(); });
dirEl.addEventListener('focus',  ()=>{ editingDir=true; stopPoll(); });
dirEl.addEventListener('blur',   ()=>{ editingDir=false; startPoll(); });
syringeEl.addEventListener('focus',  ()=>{ editingSyr=true; stopPoll(); });
syringeEl.addEventListener('blur',   ()=>{ editingSyr=false; startPoll(); });

async function getStatus(){
  try{
    const r = await fetch('/status',{cache:'no-store'});
    const j = await r.json();
    statusEl.textContent = (j.running?'Running':'Paused')
        +' | Dir: '+(j.dir?'CW':'CCW')
        +' | Syringe: '+j.mm_per_ml+' mm/mL'
        +' | Flow: '+j.mlhr.toFixed(1)+' mL/hr';
    if(!editingDir) dirEl.value = j.dir ? '1' : '0';
    if(!editingSyr) syringeEl.value = j.mm_per_ml;
    if(!editing)    mlhrEl.value = j.mlhr.toFixed(1);
  }catch(e){
    statusEl.textContent = 'Disconnected';
  }
}

async function apply(){
  const dir  = dirEl.value;
  const mlhr = mlhrEl.value;
  const syr  = syringeEl.value;
  await fetch('/set?dir='+dir+'&mlhr='+mlhr+'&syr='+syr,{cache:'no-store'});
  getStatus();
}

async function run(){ await fetch('/run?state=1',{cache:'no-store'}); getStatus(); }
async function pause(){ await fetch('/run?state=0',{cache:'no-store'}); getStatus(); }
document.getElementById('apply').addEventListener('click', apply);
document.getElementById('btnRun').addEventListener('click', run);
document.getElementById('btnPause').addEventListener('click', pause);

// Apply on Enter
mlhrEl.addEventListener('keydown', (e)=>{ if(e.key==='Enter'){ apply(); mlhrEl.blur(); }});

getStatus();
startPoll();
</script>
</body>
</html>
)HTML";

// ================== HTTP ==================
void handleRoot() { server.send(200, "text/html", PAGE); }

void handleStatus() {
  float mlhr = (halfPeriodUs > 0) ? (281250.0f * syringe_mm_per_mL / halfPeriodUs) : 0;
  String json = "{";
  json += "\"running\":"; json += (running ? "true" : "false"); json += ",";
  json += "\"dir\":";     json += (dirCW   ? "true" : "false"); json += ",";
  json += "\"mlhr\":";    json += mlhr; json += ",";
  json += "\"mm_per_ml\":"; json += syringe_mm_per_mL;
  json += "}";
  server.send(200, "application/json", json);
}

void handleRun() {
  if (server.hasArg("state")) {
    int s = server.arg("state").toInt();
    portENTER_CRITICAL(&timerMux);
    running = (s != 0);
    portEXIT_CRITICAL(&timerMux);
  }
  server.send(200, "text/plain", "OK");
}

void handleSet() {
  if (server.hasArg("dir")) {
    bool d = (server.arg("dir").toInt() != 0);
    dirCW = d;
    digitalWrite(DIR_PIN, dirCW ? HIGH : LOW);
  }
  if (server.hasArg("syr")) {
    syringe_mm_per_mL = server.arg("syr").toFloat();
    if (syringe_mm_per_mL <= 0) syringe_mm_per_mL = 1.0;
  }
  if (server.hasArg("mlhr")) {
    float v = server.arg("mlhr").toFloat();
    if (v > 0) {
      portENTER_CRITICAL(&timerMux);
      halfPeriodUs = (uint32_t)((281250.0f * syringe_mm_per_mL) / v);
      timerAlarmWrite(timer, halfPeriodUs, true);
      portEXIT_CRITICAL(&timerMux);
    }
  }
  server.send(200, "text/plain", "OK");
}

// ================== Setup helpers ==================
void setupTimer() {
  timer = timerBegin(0, 80, true);   // prescaler 80 -> 1 MHz
  timerAttachInterrupt(timer, &onTimer, true);
  timerAlarmWrite(timer, halfPeriodUs, true);
  timerAlarmEnable(timer);
}

void setupPins() {
  pinMode(DIR_PIN, OUTPUT);
  pinMode(STEP_PIN, OUTPUT);
  digitalWrite(STEP_PIN, LOW);
  digitalWrite(DIR_PIN, dirCW ? HIGH : LOW);
}

void setupAP() {
  WiFi.mode(WIFI_AP);
  bool ok = WiFi.softAP(AP_SSID, (strlen(AP_PASS)>=8)?AP_PASS:NULL, AP_CHANNEL, AP_HIDDEN, AP_MAX_CONN);
  (void)ok;
  IPAddress ip = WiFi.softAPIP();
  Serial.print("AP SSID: "); Serial.println(AP_SSID);
  if (strlen(AP_PASS)>=8) { Serial.print("AP PASS: "); Serial.println(AP_PASS); }
  Serial.print("AP IP: "); Serial.println(ip);
}

void setupServer() {
  server.on("/", handleRoot);
  server.on("/status", handleStatus);
  server.on("/run", handleRun);     
  server.on("/set", handleSet);     
  server.begin();
  Serial.println("HTTP server started");
}

void setup() {
  Serial.begin(115200);
  setupPins();
  setupAP();
  setupServer();
  setupTimer();
}

void loop() {
  server.handleClient();
}

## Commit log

2026-04-06 Additional models
    [Part Studio 1 - ActualStepper.step, Part Studio 1 - End Support.step, Part Studio 1 - Flange Connector (1).step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]
2026-04-06 Stepper control program
